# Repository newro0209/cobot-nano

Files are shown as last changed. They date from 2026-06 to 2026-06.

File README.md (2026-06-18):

# cobot-nano

SCARA robot arm, 3D-printed (FDM). Off-the-shelf parts (NopSCADlib vitamins)
maximized.

## Design
- **SCARA** kinematic chain: vertical Z translation (J1) + horizontal shoulder
  and elbow rotation (J2/J3) + tool roll (J4). See [docs/kinematic_chain.md](docs/kinematic_chain.md).
- **3D-printed (FDM)**, off-the-shelf parts maximized. Recesses, counterbores
  and press-fit seats are used freely; high-load seats are machined after
  printing (`[CNC-LATER]`).

## Layout
```
config.scad        shared spec, allowances, render settings; NopSCADlib + local vitamin includes
vitamins/          local vitamins not in NopSCADlib (mirror NopSCADlib's family-per-file layout)
  screws.scad        local M6_shoulder_screw added to NopSCADlib's screw family
  pulleys.scad       local GT2x60x8_pulley added to NopSCADlib's pulley family
parts/             fabricated parts (NopSCADlib printed/ analog) — 2D profile + extrude/pockets per module
assemblies/        integrated robot assembly preview — parts + vitamins, exploded view
docs/              kinematic chain, BOM
main.scad          full robot + animation hooks (incomplete scaffolding)
export/            cut-file generation (not yet wired)
```

## Conventions
Structure and style follow **NopSCADlib's actual layout first, then
`OPENSCAD_CONVENTIONS.md`**. There is no `plates/` / `fabrications/` split;
fabricated parts live in `parts/` like NopSCADlib's `printed/`. See `CLAUDE.md`.

## Workflow
1. Tune shared values in `config.scad` and subsystem values in
   `parts/arm_carriage_plate_base.scad`.
2. Preview: open `assemblies/robot_assembly.scad` in OpenSCAD
   (use the `bc_exploded`, `ac_exploded`, and `ua_exploded` sliders to explode stacks).
3. Headless check: `openscad -o out.echo assemblies/robot_assembly.scad`
   (only NopSCADlib's internal `2p54` deprecation should appear).

## BOM
See [docs/BOM.md](docs/BOM.md) for the arm carriage bill of materials with
CAD-derived dimensions (plate thickness, screw lengths, spacer heights).

## NopSCADlib (required)
NopSCADlib must be installed in your OpenSCAD libraries folder:
```
git clone https://github.com/nophead/NopSCADlib.git \
  "$HOME/Documents/OpenSCAD/libraries/NopSCADlib"
```
This machine's actual path: `C:\Program Files\OpenSCAD\libraries\NopSCADlib`.

Project vitamin files mirror NopSCADlib's family-per-file pattern only for parts
not provided by NopSCADlib (e.g. `M6_shoulder_screw`, `GT2x60x8_pulley`).
Existing NopSCADlib vitamins are used directly, without local wrappers.

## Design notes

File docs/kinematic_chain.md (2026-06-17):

# 기구 체인 (Kinematic Chain)

조립체·부품 명명은 아래 운동 체인을 기준으로 맞춘다.

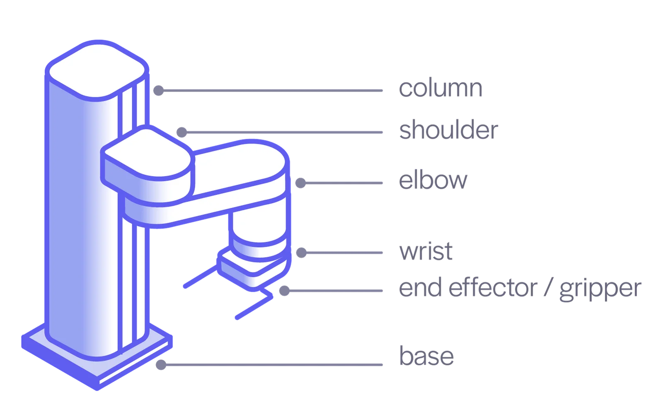
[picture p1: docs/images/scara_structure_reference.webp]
SCARA 구조 참조


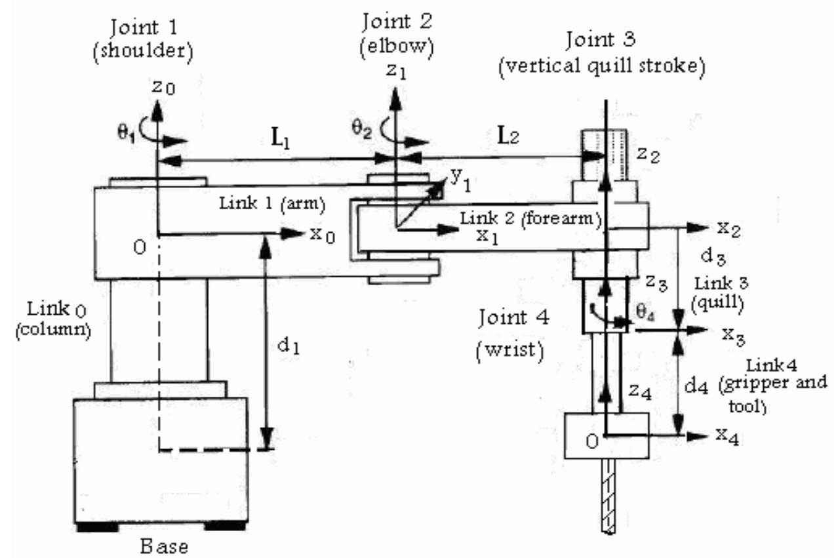
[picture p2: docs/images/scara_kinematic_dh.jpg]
SCARA DH 기구 다이어그램


```text
BASE_MOUNTING_PLATE      베이스 고정판(base mounting plate)   (고정)
-> BASE_COLUMN           베이스 기둥(base column)            (고정)
-> COLUMN_Z_SLIDE (J1)   Z 레일(Z rail)                     — Z축 병진(수직 이동)
-> ARM_CARRIAGE          암 캐리지(arm carriage)             — Z 레일 이동체, 어깨 관절 마운트
-> SHOULDER_MOUNT_LINK   어깨 마운트 링크(shoulder mount link) — 암 캐리지에서 J2 축까지 돌출된 링크
-> SHOULDER_JOINT (J2)   어깨 관절(shoulder joint)           — 수평 회전, 상완 선회
-> UPPER_ARM             상완 링크(upper arm)
-> ELBOW_JOINT (J3)      팔꿈치 관절(elbow joint)            — 수평 회전, 전완 선회
-> FOREARM               전완 링크(forearm)
-> TOOL_ROLL (J4)        툴 롤(tool roll)                   — Z축 회전, 공구 방향
-> TOOL_FLANGE           툴 플랜지(tool flange)
```

링크의 양끝은 기준부에 가까운 쪽을 `proximal pivot`(근위 피벗), 말단부에 가까운 쪽을 `distal pivot`(원위 피벗)으로 부른다.

```text
[proximal pivot] ── link body ── [distal pivot]
[근위 피벗]        ── 링크 몸체 ──  [원위 피벗]
```

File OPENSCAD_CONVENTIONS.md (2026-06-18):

---
name: openscad-conventions
description: 이 프로젝트에서 OpenSCAD 파라메트릭 모델을 설계, 구현, 수정, 리뷰할 때 적용하는 코딩 컨벤션.
version: 2.0-openscad
---

# OpenSCAD 코딩 컨벤션

> OpenSCAD는 선언형·함수형 CAD 언어다. 변수는 컴파일 시점에 확정되는 불변값이며, 재할당·반복 누적·예외 처리·객체지향 개념이 없다. 이 문서는 그 특성에 맞춰 작성되었다.

## 규칙 강도 표기

| 표기 | 의미 |
|---|---|
| **MUST** | 반드시 따른다. 위반은 잘못된 구현으로 간주한다. |
| **NEVER** | 어떤 경우에도 금지한다. |
| **SHOULD** | 기본으로 따른다. 위반 시 사유를 명시한다. |

## 충돌 시 우선순위

이 문서보다 **NopSCADlib 실제 구조/스타일**이 먼저다(프로젝트 지시: NopSCADlib → 이 문서 순). NopSCADlib가 정하지 않은 부분에서 규칙이 충돌하면 아래 항목이 우선한다.

1. **현재 부품·요구의 정확한 충족** — 지금 필요 없는 파라미터·옵션은 만들지 않는다 (YAGNI)
2. **읽기 쉬움** — 한 번에 이해되지 않는 모델은 잘못된 설계다 (KISS)
3. **의미 보존** — 이름과 구조가 기계 부품의 의미를 드러내야 한다
4. **중복 제거** — 의미를 해치면 형상 중복을 허용한다 (DRY는 최하위)

---

## 1. 네이밍 [N]

### N-1 (MUST) 이름만으로 부품·치수의 역할을 추론할 수 있어야 한다

OpenSCAD 관례에 따라 모듈·함수·변수는 `snake_case`로 작성한다.

| ✅ 권장 | ❌ 금지 |
|---|---|
| `gt2_pulley`, `bearing_seat_608zz` | `part1`, `obj`, `thing` |
| `joint_actuator_housing` | `data`, `temp`, `stuff` |
| `belt_anchor_clamp` | `helper`, `util`, `make` |
| `shoulder_bolt_clearance` | `val`, `x1`, `do_it` |

### N-2 (MUST) CAD 표준 치수 약어만 허용한다

다음 한 글자 약어는 CAD·OpenSCAD 관례상 허용한다.

> `r`(반지름) · `d`(지름) · `h`(높이) · `w`(폭) · `t`(두께) · `od`/`id`(외경/내경) · `$fn`/`$fa`/`$fs`(해상도)

그 외 임의 단축어는 금지한다. 단, N-4의 부품 패밀리 접두사처럼 파일·타입 스키마가 정의한 짧은 도메인 prefix는 임의 단축어로 보지 않는다.

| ❌ 금지 | ✅ 권장 |
|---|---|
| `cfg`, `cnt`, `tol` | `configuration`, `count`, `clearance` |
| `brg`, `plt` | `bearing`, `pulley` |
| `dia` | `diameter` (또는 `d`) |

### N-3 (SHOULD) 짧은 이름보다 오해 없는 이름

`wall` → `mounting_wall_thickness`, `gap` → `axial_clearance`
단, 명확한 지역 변수(루프 인덱스 `i`, 각도 `a`)는 예외다.

### N-4 (MUST) 단일 프로젝트 설정값에는 반복 접두사를 붙이지 않는다

이 저장소처럼 단일 로봇을 모델링하는 프로젝트는 파일과 프로젝트가 이미 맥락을 제공하므로 설정 변수에 `design_`, `spec_`, `cobot_` 같은 반복 접두사를 붙이지 않는다. 공통 기준값은 `config.scad`에 두고, 특정 부품 패밀리의 기준값과 타입 배열은 해당 plural 파일에 둔다.

단, NopSCADlib와 로컬 타입 배열의 접근자 함수는 T-2에 따라 `prefix_property(type)` 형식을 유지한다. 여러 파일이 같은 부품 패밀리의 공통 기준값을 include해 공유하는 경우에도 NopSCADlib처럼 짧고 안정적인 패밀리 prefix를 쓴다. 예를 들어 `arm_carriage_plate_base.scad`가 제공하는 전역 치수·좌표는 긴 `arm_carriage_*` 대신 `ac_*`를 사용한다.

```scad
// config.scad
sheet_thickness = 6;
main_bolt_diameter = 5;

// parts/links.scad
lower_link_length = 200;
upper_link_length = lower_link_length * upper_link_length_ratio;

// parts/arm_carriage_plate_base.scad
ac_leadnut_type = LSN8x2;
ac_motor_center = [0, 0];
ac_plate_thickness = bb_width(ac_driven_axis_ball_bearing_type) + seat_shoulder_thickness;
```

---

## 2. 파일 구조와 책임 분리 [S]

### S-1 (MUST) 파일을 다음 순서로 구성한다

```text
1. 파라미터 블록   — 모든 설정 가능한 치수·공차를 상단에 모은다
2. 함수            — 순수 계산 (피치 지름, 좌표 생성 등)
3. 부품 모듈       — 출력·가공 단위가 되는 개별 부품
4. 어셈블리 모듈   — 부품을 조합해 배치 (시각화·간섭 확인용)
5. 렌더 선택부     — 무엇을 출력할지 고르는 진입점
```

### S-2 (MUST) 한 모듈 = 한 부품, 한 함수 = 한 계산

하나의 모듈은 하나의 출력·가공 단위(또는 하나의 기능적 형상)만 담당한다.

### S-3 (MUST) 매직 넘버를 금지한다 — 모든 치수는 명명된 파라미터로

특히 **공차·클리어런스**는 반드시 명명 변수로 분리한다. 프린터·가공 방식이 바뀌면 한 곳만 고치면 되도록 한다.

```text
// 제조 공차 (한 곳에서 관리)
fdm_clearance      = 0.2;   // PETG FDM 압출 공차(extrusion tolerance)
press_fit_interference = 0.05; // 608ZZ 베어링 압입 간섭(interference fit)
axial_clearance    = 0.3;   // 회전 허브-인접부 축방향 간격(axial gap)
```

### S-4 (NEVER) 미래 부품을 가정한 파라미터·옵션 선제작 금지

지금 만드는 부품에 필요 없는 분기·옵션 인자를 미리 넣지 않는다.

### S-5 (MUST) 형상 공통화 게이트 — 아래를 **모두** 만족할 때만 모듈로 추출한다

1. 동일 형상이 **3회 이상** 반복됨
2. 의미가 동일함 (우연히 모양만 같은 것은 중복이 아님)
3. 추출 후 이름이 더 명확해짐
4. 치수 변경 방향이 같다고 확신할 수 있음

하나라도 불충족 → 형상을 그대로 둔다. 볼트 구멍 하나를 성급히 모듈화하지 않는다.

### S-6 (MUST) `config.scad`와 plural 파일의 기준값 책임을 분리한다

`config.scad`에는 제조 공차, 렌더 해상도, 체결 부품 선택처럼 여러 계층이 공유하는 기준값을 둔다. 특정 서브시스템의 치수·좌표·타입은 해당 part 파일에서 짧은 패밀리 접두사로 둔다.

```scad
// config.scad
clearance = 0.1;
$fn = 56;
main_bolt_diameter = 5;

// parts/arm_carriage_plate_base.scad
ac_plate_thickness = bb_width(ac_driven_axis_ball_bearing_type) + seat_shoulder_thickness;
ac_motor_center = [0, 0];
```

### S-7 (MUST) 연결된 치수는 비율로 파생한다

직접 mm 값을 두는 대상은 기준 링크 길이, 판재 두께, 볼트 지름처럼 외부 제약이나 설계 의사결정으로 독립적으로 정해지는 값으로 제한한다. lazy-susan처럼 외부 부품을 선택하는 타입도 독립 기준으로 볼 수 있다. 그 기준에 연결된 길이·간격·폭은 별도 mm 값으로 다시 쓰지 않고 비율이나 함수로 계산한다.

```scad
// parts/links.scad
lower_link_length = 200;
upper_link_length_ratio = 1.2;
link_width_ratio = 0.15;

upper_link_length = lower_link_length * upper_link_length_ratio;
link_width = lower_link_length * link_width_ratio;

// config.scad
base_bearing = BB6808;
base_diameter_ratio = 1.6;
base_diameter = bb_diameter(base_bearing) * base_diameter_ratio;
```

### S-8 (NEVER) 로봇 전체 설계를 타입 배열/접근자 레이어로 감싸지 않는다

타입 배열과 `prefix_property(type)` 접근자는 NopSCADlib식 vitamin 데이터처럼 독립 부품의 스키마가 명확할 때 사용한다. 로봇 전체 어셈블리의 임시 설계값을 배열 하나와 수십 개의 접근자 함수로 감싸지 않는다.

### S-9 (MUST) 부품·vitamin·조립체 계층을 분리한다 (NopSCADlib 구조)

3D 프린팅 프로젝트는 NopSCADlib 구조를 따른다.

```text
vitamins/      구입 부품 — NopSCADlib에 없는 로컬 타입만(패밀리당 한 파일로 미러링)
parts/         제작(프린트) 부품 — NopSCADlib printed/ 대응, 2D 프로파일 + 압출/포켓을 한 모듈에
assemblies/    parts와 vitamins를 배치해 기능 조립체 구성
```

`parts/`는 인터페이스 치수를 NopSCADlib 접근자로 읽고 하드코딩하지 않는다. `assemblies/`는 `parts/`와 `vitamins/`를 배치한다. 옛 `plates/`·`fabrications/` 2D 절단 분리는 쓰지 않는다(NopSCADlib에 없는 구조).

### S-10 (MUST) 같은 스키마의 2D 프로파일 변형은 타입 배열로 통합한다

같은 기계적 의미와 스키마를 가진 2D 프로파일이 여러 개 필요하면 개별 파일과 개별 모듈을 늘리지 않는다. 단일 프로파일 파일에 타입 배열 스키마, `prefix_property(type)` 접근자, `prefix_2d(type)` 모듈을 두고, 타입 인스턴스는 같은 폴더의 plural 파일에서 정의한다.

```scad
function link_length(type) = type[1];

module link_2d(type) {
    // 피벗 구멍(pivot hole)은 회전 조인트(revolute joint)가 축 기준으로 움직일 조립 여유(clearance)를 만든다.
    // ...
}

// parts/links.scad
//                name          length             width       bolt_diameter       profile_width_ratio
lower_link_type = ["lower_link", lower_link_length, link_width, main_bolt_diameter, 1.0];
upper_link_type = ["upper_link", upper_link_length, link_width, main_bolt_diameter, 1.0];
```

단, 우연히 모양만 같고 설계 변경 방향이나 기계적 의미가 다르면 S-5에 따라 공통화하지 않는다.

---

## 3. 타입 배열과 접근자 함수 [T]

NopSCADlib는 객체처럼 보이는 부품 데이터를 배열로 표현한다. 배열의 0번 요소는 대체로 이름이나 코드이고, 이후 요소는 치수와 속성이다.

```scad
BB608 = ["608", 8, 22, 7, "black", 1.4, 2.0, 0, 0];
```

### T-1 (MUST) 타입 배열은 기존 인덱스 방식으로 정의한다

배열 인덱스는 타입 정의부와 접근자 함수 내부에만 둔다. 호출부에 `type[2]` 같은 직접 접근을 노출하지 않는다.

### T-2 (MUST) 접근자 함수는 `prefix_property(type)` 형식을 따른다

접근자 함수는 짧고 안정적인 접두사를 사용한다. 기존 파일에서 쓰는 접두사가 있으면 바꾸지 않는다.

```scad
function bb_name(type)     = type[0]; //! Part code without shield type suffix
function bb_bore(type)     = type[1]; //! Internal diameter
function bb_diameter(type) = type[2]; //! External diameter
```

파생값도 접근자 함수로 표현한다. 원본 배열에 중복 저장해서 불일치를 만들지 않는다.

```scad
function gridfinity_bin_size_mm(type) =
    gridfinity_bin_size(type) * gridfinity_pitch();
```

### T-3 (SHOULD) 생성자 함수는 필요한 경우에만 둔다

복잡한 printed part처럼 사용자가 타입 배열을 직접 만들 가능성이 높으면 생성자 함수를 둘 수 있다. 생성자 이름은 대상 타입명과 같게 두는 기존 패턴을 우선한다.

```scad
function knob(name = "knob", top_d = 12, bot_d = 15, height = 18, shaft_length, ...) =
[
    name, top_d, bot_d, height, ...
];
```

### T-4 (MUST) 배열 스키마 주석을 유지한다

타입 목록 파일에는 열 의미를 알려주는 정렬 주석을 유지한다. 새 필드를 추가하면 주석, 접근자 함수, 타입 목록, 테스트를 함께 갱신한다.

```scad
//          name     id od   w    color
BB608    = ["608",   8, 22,  7,   "black"];
```

---

## 4. 모듈과 함수 [M]

### M-1 (MUST) 역할을 분리한다 — 모듈은 형상, 함수는 값

- **module**: 지오메트리를 생성한다. 값을 반환하지 않는다.
- **function**: 값을 계산해 반환한다. 형상을 만들지 않는다.

```text
// 함수: 값 계산
function gt2_pitch_diameter(teeth, pitch = 2) = teeth * pitch / PI;

// 모듈: 형상 생성
module gt2_pulley(teeth, bore_diameter, height) {
  assert(teeth > 0, "치아 수(teeth)는 양수여야 합니다");
  // ...
}
```

### M-2 (MUST) 명명 인자와 기본값을 사용한다 — 불리언·위치 인자 나열 금지

호출부에서 각 숫자의 의미가 드러나야 한다.

```text
❌ belt_anchor(12, 3, 5, true, false)
✅ belt_anchor(clamp_width = 12,
               bolt_diameter = 3,
               wall = 5,
               dual_end = true)
```

### M-3 (SHOULD) 반복·배치는 `children()`을 받는 고차 모듈로 분리한다

배치 로직과 형상 정의를 섞지 않는다.

```text
module radial_array(count, radius) {
  for (i = [0 : count - 1])
    rotate([0, 0, i * 360 / count])
      translate([radius, 0, 0])
        children();
}

radial_array(count = 6, radius = 20) bolt_hole(d = 3);
```

### M-4 (SHOULD) 불리언 연산 중첩을 평평하게 유지한다

`difference`/`union`이 3단계 이상 깊어지면 의미 있는 중간 모듈로 분리한다.

---

## 5. 선언적·파라메트릭 설계 [P]

### P-1 (MUST) 명령형 누적 대신 리스트 컴프리헨션으로 표현한다

OpenSCAD에는 가변 상태가 없다. 반복 데이터는 선언적으로 생성한다.

```text
// 섹터 기반 구동 요소의 둘레 좌표
tooth_points = [ for (a = [0 : tooth_angle : 360 - tooth_angle])
                   [cos(a) * pitch_r, sin(a) * pitch_r] ];
```

### P-2 (MUST) 함수 내 지역 바인딩은 `let()`으로 명시한다

```text
function planetary_output_speed(input_rpm, ratio) =
  let (output = input_rpm / ratio)
  output;
```

### P-3 (SHOULD) 2D 스케치 후 압출하는 선언적 패턴을 우선한다

`linear_extrude`, `rotate_extrude`로 단면을 먼저 정의하면 의도가 분명해지고 수정이 쉽다. 3D 프리미티브를 즉흥적으로 깎는 방식보다 우선한다.

### P-4 (MUST) 파생 치수는 저장하지 말고 함수로 계산한다

피치 지름, 중심 거리처럼 다른 값에서 계산되는 치수는 별도 변수로 중복 정의하지 않고 함수로 도출한다. 원본 치수와 파생 치수가 어긋나는 것을 방지한다.

---

## 6. 검증과 해상도 [V]

### V-1 (MUST) 기하학적 전제는 `assert()`로 강제한다

벽 두께가 음수가 되거나 구멍이 외경보다 큰 경우처럼 물리적으로 불가능한 입력을 컴파일 시점에 차단한다.

```text
module bearing_seat(outer_diameter, wall) {
  assert(wall > 0, "벽 두께(wall)는 0보다 커야 합니다");
  assert(outer_diameter > 0, "외경(outer diameter)은 양수여야 합니다");
  // ...
}
```

### V-2 (SHOULD) 디버깅 값은 `echo()`로 노출한다

조립 간섭이나 계산된 중심 거리 같은 핵심 수치를 콘솔로 확인할 수 있게 한다.

```text
echo(belt_center_distance = gt2_center_distance(driver_teeth, driven_teeth));
```

### V-3 (MUST) 해상도를 의도적으로 관리한다

- 전역 기본은 `$fa`/`$fs`로 설정한다.
- 특정 부품에만 높은 해상도가 필요하면 해당 모듈에서 `$fn`을 지역 지정한다.
- 모든 형상에 무분별하게 큰 `$fn`을 박지 않는다. 미리보기·렌더 시간이 폭증한다.

---

## 7. 주석 [C]

### C-1 (MUST) 주석은 "왜"만 설명한다

치수의 출처나 비자명한 제약의 이유를 적는다. 코드가 명백히 보여주는 것은 반복하지 않는다.

```text
❌ // 원기둥을 만듭니다.
✅ // 6810ZZ 외경 65mm + 압입 간섭 0.05mm 기준
   bearing_bore = 65 - press_fit_interference;
```

### C-2 (MUST) 주석과 문서는 한국어로 작성한다. 기계 용어는 한국어(영어) 병기한다

예: `// 숄더 볼트(shoulder bolt)가 고정축 역할을 하므로 베어링 내경에 맞춘다`

### C-3 (MUST) 파일 최상단 주석은 영어 설명 뒤 한국어 요약을 붙인다

파일 최상단 주석은 먼저 영어 문단으로 파일의 역할과 계층을 설명하고, 바로 뒤에 한국어 요약을 붙인다. 영어 설명은 외부 라이브러리·툴과 함께 읽히는 파일 헤더 역할을 하고, 한국어 요약은 프로젝트 내부 의사결정을 빠르게 확인하기 위한 것이다.

```scad
// parts/ball_bearing_seat.scad - Ball-bearing seat geometry cut into / added to printed plates (NopSCADlib printed-part style).
// Dimensions come from a NopSCADlib ball-bearing type so the seat tracks the bought bearing, not a hardcoded number.
//
// 베어링을 앉히기 위해 프린트 판재에 깎거나(음형) 덧대는(양형) 제작 형상이다.
// 치수는 NopSCADlib 베어링 타입에서 접근자로 읽어 하드코딩을 피한다.
```

### C-4 (MUST) 모듈 내부 주석은 한국어로 쓰고, 기계 원리를 설명한다

모듈 내부 주석은 한국어를 사용한다. 기계공학과 관련된 전문 용어는 반드시 `한국어(영어)` 형식으로 병기하고, 단순 명칭만 적지 말고 그 구조가 어떤 원리로 쓰이는지 설명한다.

```scad
// 외륜 림(outer-race rim)만 단차로 물어, 회전하는 내륜(inner race)과 실드를 건드리지 않는다.
translate(ac_driven_axis_center)
    bb_bearing_seat_pocket(ac_driven_axis_ball_bearing_type, part_thickness = ac_plate_thickness, from_top = true);
```

### C-4a (MUST) `seat_shoulder_thickness`는 파는 깊이가 아니라 남기는 두께다

포켓·시트에서 `seat_shoulder_thickness`는 **반대쪽에 남길 축방향 지지 두께**다. 카운터보어 또는 리세스 깊이는 `part_thickness - seat_shoulder_thickness`에서 계산해야 하며, 각 단계를 `seat_shoulder_thickness`만큼만 파는 값으로 쓰지 않는다.

```scad
// 권장: 가장 깊은 리세스 뒤에 shoulder를 남긴다.
seat_depth = part_thickness - seat_shoulder_thickness;
cylinder(d = seat_diameter, h = seat_depth + eps);

// 금지: shoulder 두께만큼만 시트를 얕게 판다.
cylinder(d = seat_diameter, h = seat_shoulder_thickness + eps);
```

다단 포켓은 얕은 단부터 깊은 단까지 누적 깊이로 계산한다. 예를 들어 모터 시트는 `body_recess_depth + NEMA_boss_height(type) == part_thickness - seat_shoulder_thickness`가 되도록 잡고, 샤프트 보어처럼 실제 관통이 필요한 형상만 남은 shoulder를 통과시킨다.

### C-5 (SHOULD) 코드 옆 주석은 `대상 용어(구) — 역할/이유(절)` 형식으로 쓴다

코드 바로 옆 주석은 `대상 용어(English term) — 역할/이유` 형식으로 쓴다. 앞의 **대상 용어는 짧은 구(phrase)**로, 뒤의 **역할/이유는 동사로 끝나는 절(clause)**로 쓴다(역할/이유를 명사구로 끊지 않는다). 기계적 역할과 제약이 한눈에 읽히도록 하고, `공칭 지름(nominal diameter, 호칭 치수)`처럼 오해될 수 있는 전문어는 괄호 안에 영어와 짧은 해석을 함께 붙인다.

```scad
// 외륜 숄더(outer-race shoulder) — 내륜(inner race) 바깥에서만 축방향으로 받쳐, 회전하는 내륜과 실드를 건드리지 않는다.
circle(d = inner_race_outside_diameter + bearing_clearance);
```

대상 용어가 자명하면 `—` 없이 역할/이유 절만 써도 된다. 단, 파일 헤더처럼 독립 문맥이 필요한 주석이나 복잡한 설계 의사결정은 C-1에 따라 여러 문장으로 이유를 설명할 수 있다.

### C-6 (SHOULD) 후속 가공 부위는 `[CNC-LATER]` 태그로 표기한다

FDM 프로토타입 후 절삭 가공할 구조적 임계부를 주석으로 명시해 추후 검색·교체가 쉽도록 한다.

```text
// [CNC-LATER] 고하중 피벗(high-load pivot) 베어링 시트, 프린트 후 보링 가공
```

---

## 8. 외부 라이브러리 [L]

### L-1 (MUST) `use`와 `include`를 구분해 쓴다

- `use <lib.scad>`: 모듈·함수만 가져온다 (최상위 형상 실행 안 함). **기본값**.
- `include <lib.scad>`: 파일 전체를 펼친다. 최상위 형상이 함께 실행되므로 신중히 쓴다.

### L-2 (MUST) 부품을 만들기 전에 NopSCADlib 존재 여부를 먼저 확인한다

기성품, 체결 부품, 모터, 베어링, 풀리처럼 vitamin 성격의 부품은 직접 모델링하거나 치수를 하드코딩하기 전에 `NopSCADlib/vitamins`에 같은 부품이 있는지 확인한다.

- 있으면 NopSCADlib의 타입 배열, 접근자 함수, 모듈을 그대로 사용한다.
- 없으면 프로젝트 `vitamins/`에 NopSCADlib의 단수/복수 파일 패턴으로 로컬 vitamin을 만든다.
- 확인 없이 로컬 모델, 래퍼, 임의 치수 상수를 만들지 않는다.

### L-3 (MUST) 라이브러리 부품 치수는 접근자로 읽는다

NopSCADlib가 제공하는 타입 배열의 치수는 숫자로 복사하지 않는다. 호출부와 제작 파트는 라이브러리 접근자를 통해 값을 읽는다.

```scad
// 금지: NEMA17 값 복사
NEMA17_HOLE = 31;
NEMA17_BORE = 23;

// 권장: NopSCADlib 접근자 사용
hole_pitch = NEMA_hole_pitch(NEMA17_40);
boss_clearance_r = NEMA_big_hole(NEMA17_40);
body_width = NEMA_width(NEMA17_40);
```

로컬 vitamin도 같은 원칙을 따른다. 예를 들어 lazy-susan의 외경과 장착 홀 피치는 `ls_diameter(type)`, `ls_bolt_circle_diameter(type)`처럼 접근자로 읽는다.

### L-4 (MUST) 라이브러리 도입 게이트 — 모두 만족할 때만 도입한다

1. 직접 구현보다 유지 비용이 낮음 (예: BOSL2의 나사산·기어)
2. 유지보수 상태가 안정적
3. 모델 핵심 복잡도를 실제로 줄임
4. 기존 코드·치수 체계와 충돌하지 않음

### L-5 (NEVER) 라이브러리가 이미 제공하는 vitamin을 의미 없이 래핑하지 않는다

NopSCADlib처럼 타입 배열, 접근자 함수, 모듈을 이미 제공하는 부품은 원래 파일과 이름을 그대로 사용한다. 프로젝트 파일은 라이브러리에 없는 부품을 추가하거나, 실제로 다른 인터페이스·의미를 제공할 때만 만든다.

---

## 9. 조립 라벨 오버레이 [A]

조립체(`assemblies/`)에는 부품을 지목하는 프리뷰 전용 라벨 오버레이를 둘 수 있다. 구현은 `assemblies/annotations.scad`(빌보드 텍스트·지시선·자동 배치 모듈)와 호출부(`robot_assembly.scad`의 assembly section별 label module)를 기준으로 한다.

### A-1 (MUST) 라벨은 `$preview` 전용이며 형상에 영향을 주지 않는다

모든 라벨 모듈은 `$preview` 가드 안에서만 그리고, 글자는 얇은 `linear_extrude`로 만든다. STL·절단·간섭 형상에는 들어가지 않는다.

### A-2 (SHOULD) 라벨 위치는 고정값이 아니라 뷰포트와 부품 좌표로 계산한다

지시선 lead를 손으로 박지 않는다. 부품 점과 뷰포트 회전(`$vpr`)에서 화면축(화면 우/상/법선)을 유도해 라벨을 화면 좌/우 열에 자동 분배하고, 열 안에서 균등 간격으로 펼쳐 겹치거나 가리지 않게 한다(`callout_field`). 카메라를 돌리면 라벨도 따라 재배치된다.

### A-3 (MUST) 라벨 색은 대상 부품의 렌더 색과 같게 한다

부품 색을 한 곳(예: `asm_col_*`)에 정의해 그리기와 라벨이 같은 변수를 공유한다. 라벨·지시선·점을 그 색으로 그려 어느 부품을 가리키는지 색으로도 잇는다. 내부 고정색 vitamin(NopSCADlib 모터·베어링·체결구)은 재질색으로 근사한다. 글자 가독성을 위해 명도 기준 대비 테두리(`contrast_outline`)를 덧댄다 — 회색 계열은 RGB 보색이 다시 회색이라 대비가 안 나므로 흑/백을 쓴다.

### A-4 (MUST) exploded에서 라벨은 대상과 같은 변환으로 따라 움직인다

부품이 받는 분해 변환(거리비례 bloom + explode Z)을 라벨 점에도 그대로 적용한다(`label_point`). 분해해도 라벨이 부품에 붙어 있어야 한다.

### A-5 (SHOULD) 라벨은 종류 토글로 끄고 켠다

기능군으로 토글을 나눈다 — 체결구 / 구조·개념(관절·축·링크) / 동적 기성품(모터·풀리·벨트·베어링·이송나사). 체결구는 라벨만 보고 조립할 수 있을 만큼 위치·역할까지 빠짐없이 달고(중복 허용), 구조는 J1/J2 같은 관절·축과 링크 개념을 빠짐없이 단다. 데이터 스키마는 `[텍스트, 점, 그룹, 강조, bloom, ez, 색]`을 쓴다.

---

## 작업 절차

부품 추가·수정 시 아래 순서를 따른다.

1. 만들 부품을 **한 문장**으로 정의한다 (예: "608ZZ 2개를 지지하는 J2 팔꿈치 베어링 하우징")
2. 해당 부품이나 인접 vitamin이 NopSCADlib에 있는지 먼저 확인한다 (L-2)
3. NopSCADlib에 있으면 원본 타입·모듈·접근자로 인터페이스 치수를 읽는다 (L-3)
4. 인접 부품과의 인터페이스 치수·공차를 먼저 파라미터로 정리한다
5. 파생 치수를 함수로 분리한다
6. 2D 단면 → 압출 가능한지 먼저 검토한다
7. 제작 부품은 `parts/`에 NopSCADlib printed/ 스타일로 두고, 구입 부품은 `vitamins/`에 둔다 (S-9)
8. 같은 스키마의 반복 2D 프로파일이면 타입 배열과 접근자 함수로 통합한다 (S-10, T-1, T-2)
9. 이름을 확정한 뒤 모듈을 구현한다
10. 반복 형상은 즉시 모듈화하지 말고 S-5 게이트를 검사한다
11. `assert()`로 기하 전제를 건다
12. 더 단순하게 줄일 수 있는지 마지막으로 검토한다

---

## 셀프 리뷰 체크리스트

제출 전 **모든** 항목을 통과해야 한다.

- [ ] 이름만 보고 부품·치수 역할을 이해할 수 있는가? (N-1)
- [ ] 공통 기준값은 `config.scad`, 특정 부품 패밀리 값과 타입 배열은 plural 파일에 있으며 반복 접두사를 쓰지 않는가? (N-4, S-6)
- [ ] 매직 넘버 없이 공차·치수가 명명 파라미터로 분리됐는가? (S-3)
- [ ] vitamin 성격의 부품을 만들기 전에 NopSCADlib 존재 여부를 확인했는가? (L-2)
- [ ] NopSCADlib 제공 부품의 치수를 숫자로 복사하지 않고 접근자로 읽는가? (L-3)
- [ ] 부품·vitamin·조립체 계층이 `parts/`, `vitamins/`, `assemblies/`로 분리됐는가? (S-9)
- [ ] 타입 배열을 직접 인덱싱하지 않고 접근자 함수로만 읽는가? (T-1, T-2)
- [ ] 같은 스키마의 반복 2D 프로파일을 개별 파일로 늘리지 않고 타입 배열로 통합했는가? (S-10)
- [ ] 타입 배열의 주석, 접근자 함수, 타입 목록, 테스트가 함께 갱신됐는가? (T-4)
- [ ] 한 모듈이 한 부품, 한 함수가 한 계산만 하는가? (S-2, M-1)
- [ ] 지금 부품에 불필요한 옵션을 미리 만들지 않았는가? (S-4)
- [ ] 형상 추출이 의미를 해치지 않았는가? (S-5)
- [ ] 호출부가 명명 인자로 읽히는가? (M-2)
- [ ] 파생 치수를 중복 저장하지 않고 함수로 도출했는가? (P-4)
- [ ] 물리적으로 불가능한 입력을 `assert()`로 막았는가? (V-1)
- [ ] 해상도(`$fn`/`$fa`/`$fs`)를 의도적으로 관리했는가? (V-3)
- [ ] 파일 최상단 주석이 영어 설명 뒤 한국어 요약 형식인가? (C-3)
- [ ] 모듈 내부 주석이 한국어이며 기계 용어를 한국어(영어)로 병기하고 원리를 설명하는가? (C-4)
- [ ] 불리언 연산 중첩이 평평하게 읽히는가? (M-4)
- [ ] 조립 라벨이 `$preview` 전용이고, 색은 대상과 같으며, exploded에서 함께 움직이는가? (A-1, A-3, A-4)

하나라도 실패하면 해당 규칙 ID 기준으로 수정한 뒤 재검사한다.

---

## 최종 판단 기준

이 문서와 충돌하는 모델보다, 이 문서에 맞춰 **단순하고 명확하게 다시 작성한 파라메트릭 모델**을 우선한다.

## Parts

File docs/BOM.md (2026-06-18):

# BOM

이 문서는 현재 `config.scad`와 `assemblies/robot_assembly.scad` 기준의 수동 BOM입니다.
수량이 실제 assembly에 배치된 항목과 config에만 선언된 상위 J1 인터페이스 항목을 분리합니다.
구매 전에는 OpenSCAD echo와 공급사 도면을 다시 확인합니다.

## Arm Carriage Assembly

`assemblies/robot_assembly.scad` 안의 `arm_carriage_assembly()` 스택에 실제 배치되는 캐리지 기준입니다.

| 분류 | 품목 | CAD 타입 / 사양 | 수량 | 비고 |
|---|---|---|---|---|
| 제작품 | Arm carriage top plate | `parts/arm_carriage_top_plate.scad`, t=9mm | 1 | 상판, J1 리드너트와 J2 모터 슬롯 포함 |
| 제작품 | Arm carriage bottom plate | `parts/arm_carriage_bottom_plate.scad`, t=9mm | 1 | 하판, J2 종동축 하부 베어링 시트 포함 |
| 모터 | J2 stepper motor | `NEMA17_47` | 1 | 어깨 회전 구동 모터 |
| 풀리 | J2 drive pulley | `GT2x20um_pulley`, GT2 20T | 1 | NEMA17 모터축 구동 풀리 |
| 풀리 | J2 driven pulley | `GT2x60x8_pulley`, GT2 60T, 8mm bore | 1 | 3:1 감속 출력 풀리, 로컬 vitamin |
| 벨트 | J2 closed-loop timing belt | `GT2x6` | 1 | 표준 후보 298..312mm, 권장 306mm |
| 베어링 | J2 ball bearing | `BB608` (8x22x7) | 2 | J2 종동축 상/하 지지 |
| 베어링 | J1 linear bearing | `LM8UU` | 3 | 3개 가이드 로드용 캐리지 베어링 |
| 리드너트 | J1 leadnut | `LSN8x2` | 1 | 상판 아랫면 시트에 장착 |
| 스탠드오프 | Female-female hex pillar | `M3x25_ff_hex_pillar`, M3 x 25mm | 4 | 활성 인덱스 `[0, 1, 3, 4]`; 모터 슬롯 쪽 `[2, 5, 6, 7]` 제외 |
| 체결류 | Standoff screws | `M3_cap_screw`, L=16mm + washer | 8 | 필러 4개 x 상/하 2개 |
| 체결류 | Leadnut flange screws | `leadnut_screw(LSN8x2)`, L=16mm + washer + nut | 4 | 리드너트 플랜지 체결 |
| 체결류 | J2 shoulder screw | `M6_shoulder_screw`, shoulder dia 8mm, CAD shoulder length 70.6mm + `M8_washer` (머리 밑) | 1 | BB608 보어와 상/하 FC 허브를 관통하는 J2 고정 피벗 |
| 체결류 | J2 shoulder locknut | `M6_nut` (nyloc) + `M6_washer` | 1 set | 하단 FC 아래에서 스택 축방향 고정 |
| 커플링 | J2 driven flange coupling | `FC8`, 8mm bore, 4×M4 볼트원 | 2 | 어깨축 상/하단 링크 마운트, 숄더 봉을 grub screw로 죔, 로컬 vitamin |

## Configured J1 Interface

다음 항목은 `config.scad`에 J1 축 인터페이스로 선언되어 있고, `robot_assembly.scad`의 base-column 쪽 배치를 기준으로 재점검이 필요합니다.

| 분류 | 품목 | CAD 타입 / 사양 | 기준 수량 | 비고 |
|---|---|---|---|---|
| 모터 | J1 stepper motor | `NEMA17_34` | 1 | Z 병진축 구동 모터 |
| 커플링 | J1 shaft coupling | `SC_5x8_rigid` | 1 | 모터 5mm 축과 T8 리드스크류 8mm 축 직결 |
| 리드스크류 | J1 lead screw | T8x2, 8mm shaft | 1 | 길이는 아직 BOM에서 확정하지 않음 |
| 베어링 블록 | J1 flange bearing block | `KFL08`, 8mm bore | 1 | 로컬 vitamin, 리드스크류 회전 지지 |
| 가이드 로드 | J1 guide rod | 8mm shaft | 3 | `LM8UU`와 `FC8` bore 기준 |
| 플랜지 커플링 | Guide rod flange coupling | `FC8`, 8mm bore | 각 로드 끝단 수량 확정 필요 | 가이드 로드 단판 고정용 로컬 vitamin |

## 주요 CAD 파생 치수

| 항목 | 값 | 출처 |
|---|----|---|
| 캐리지 판 두께 | 9mm | `ac_thickness = bb_width(BB608) + seat_shoulder_thickness` |
| 상/하판 사이 간격 | 25mm | `ac_plate_gap = pillar_height(standoff_pillar_type)` |
| J1 중심축 - J2 어깨축 거리 | 70mm | `shoulder_mount_link_length` |
| J2 모터 슬롯 이동량 | 8mm | `ac_j2_motor_slot_travel` |
| J2 풀리 중심거리 min/current/max | 108.15 / 112.15 / 116.15mm | `ac_j2_belt_distance_*` echo (current=모터 슬롯 위치) |
| J2 벨트 정확 길이 min/current/max | 297.801 / 305.747 / 313.697mm | `ac_timing_belt_length_*` echo |
| J2 GT2 표준 폐루프 벨트 후보 | 298..312mm, nominal 306mm | `ac_timing_belt_standard_*` echo |
| 스탠드오프 체결 스크류 길이 | 16mm | `ac_standoff_screw_length` |
| 리드너트 체결 스크류 길이 | 16mm | `screw_length(leadnut_screw(j1_leadnut_type), ac_thickness, 2, nut = true)` |
| J2 숄더 길이 계산값 | 70.6mm | `ac_j2_shoulder_length` (판 스택 + 2×`fc_height(FC8)` + 머리 와셔) |

## Local Vitamins

| 파일 | 타입 | 역할 |
|---|---|---|
| `vitamins/pulleys.scad` | `GT2x60x8_pulley` | J2 60T, 8mm bore 종동 풀리 |
| `vitamins/screws.scad` | `M6_shoulder_screw` | J2 BB608 보어용 8mm shoulder screw |
| `vitamins/pillars.scad` | `M3x25_ff_hex_pillar` | 상/하판 연결용 양끝 암나사 M3 필러 |
| `vitamins/flange_bearing_blocks.scad` | `KFL08` | J1 리드스크류용 8mm 플랜지 베어링 블록 |
| `vitamins/flange_couplings.scad` | `FC8` | J1 가이드 로드 단부 고정용 8mm 플랜지 커플링 |

## Notes

- J2 벨트 장력은 아이들러가 아니라 `ac_j2_motor_slot_travel` 범위에서 모터 전체를 -Y 방향으로 이동해 조절합니다.
- `GT2x60x8_pulley`, `M6_shoulder_screw`, `M3x25_ff_hex_pillar`, `KFL08`, `FC8`은 프로젝트 로컬 vitamin입니다.
- `M6_shoulder_screw`의 70.6mm는 CAD 계산 shoulder 길이입니다. 실제 구매 규격은 가장 가까운 표준 ISO 7379 shoulder length를 선택해야 합니다.
- J1 리드스크류 길이, 가이드 로드 길이, FC8 수량은 아직 현재 캐리지 assembly만으로 확정하지 않습니다.

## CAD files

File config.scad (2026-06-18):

// config.scad - Project-wide shared values for the cobot-nano arm carriage subsystem.
// Holds manufacturing allowances, render resolution, and shared geometry constants, and pulls in the
// NopSCADlib vitamin families plus the project-local vitamin extensions (vitamins/screws, vitamins/pulleys).
//
// 프로젝트 공통값 — 제조 공차(manufacturing allowance), 렌더 해상도, 공유 형상 기준값을 둔다.
// NopSCADlib vitamin 패밀리와 프로젝트 로컬 vitamin 확장(vitamins/screws, vitamins/pulleys)을 함께 가져온다.
// 작은 fudge 값(coincident-face 방지)은 NopSCADlib 전역 `eps`(=1/128)를 그대로 쓴다 — 별도 정의하지 않는다.

include <NopSCADlib/lib.scad>
include <vitamins/pillars.scad>               // 로컬 M3x25_ff_hex_pillar (+ NopSCADlib pillar 패밀리)
include <vitamins/screws.scad>                // 로컬 M6_shoulder_screw (+ NopSCADlib screw 패밀리)
include <vitamins/pulleys.scad>               // 로컬 GT2x60x8_pulley (+ NopSCADlib pulley 패밀리)
include <vitamins/rods.scad>                  // 로컬 J1_guide_rod / T8x2_lead_screw (+ NopSCADlib rod 모듈)
include <vitamins/flange_couplings.scad>      // 로컬 FC8 플랜지 커플링 (NopSCADlib 미수록)
include <vitamins/flange_bearing_blocks.scad> // 로컬 KFL08 플랜지 베어링 블록 (NopSCADlib 미수록)

// 제조 공차(manufacturing allowance) — 가공/프린트 방식이 바뀌면 여기 한 곳만 고친다.
clearance           = 0.1;  // 부품 간 일반 끼움 간격(general fit) — 간섭(interference) 방지
bearing_clearance   = 0.1;  // 베어링 시트(bearing seat)와 베어링 사이 — 조립 편차·윤활유 수용
shaft_clearance     = 0.5;  // 샤프트 관통홀(shaft through-hole) — 오차·회전축 조립 편차 흡수
min_printed_feature = 0.8;  // FDM 최소 인쇄 두께(≈2 레이어) — 이보다 얇은 부싱/스페이서는 인쇄 대신 와셔로 흡수해 생략

// 공유 형상 기준값(shared geometry)
seat_shoulder_thickness = 2;   // 포켓·리세스 바닥에 남기는 축방향 지지 단차(seat shoulder)
component_margin        = 6;  // 조립 부품 간 최소 간격 — 조립 편차·시각적 명확성 확보

// J1 축 중심 좌표
j1_axis_center = [0, 0];

// ── J1 축(Z 병진, prismatic joint) — 리드스크류로 캐리지를 수직 이송한다 ──
// 모터를 강성 커플링(rigid coupling)으로 리드스크류에 직결하고, 캐리지에 고정된 리드너트(lead nut)가
// 스크류 회전을 직선 이송으로 바꾼다. 가이드 로드(guide rod) 3개가 LM8UU로 캐리지를 직선 안내하고,
// 로드 양끝은 플랜지 커플링으로 단판(end plate)에 수직 고정된다.
j1_motor_type                = NEMA17_34;     // Z 이송 구동 모터
j1_shaft_coupling_type       = SC_5x8_rigid;  // 모터 5mm 축 ↔ 리드스크류 8mm 축 강성 직결
j1_lead_screw_type           = T8x2_lead_screw; // T8x2 리드스크류 — NopSCADlib leadscrew() 렌더 사양
j1_leadnut_type              = LSN8x2;         // T8x2 리드너트 — 회전을 병진으로 변환(리드 2mm/rev)
j1_flange_bearing_block_type = KFL08;          // 리드스크류 회전을 받는 플랜지 베어링 블록
j1_linear_bearing_type       = LM8UU;          // 가이드 로드 직선 베어링
j1_guide_rod_type            = J1_guide_rod;   // LM8UU와 FC8이 공유하는 8mm smooth guide rod
j1_flange_coupling_type      = FC8;            // 가이드 로드 끝을 단판에 수직 고정하는 커플링
// 가이드 로드는 LM8UU가 타는 봉이자 FC8이 무는 봉 — 한 봉을 공유하므로 두 부품의 호칭 지름이 같아야 한다.
assert(smooth_rod_diameter(j1_guide_rod_type) == bearing_rod_dia(j1_linear_bearing_type),
       "J1 가이드 로드 지름은 LM8UU 가이드 베어링 지름과 같아야 한다");
assert(smooth_rod_diameter(j1_guide_rod_type) == fc_bore(j1_flange_coupling_type),
       "J1 가이드 로드 지름은 FC 플랜지 커플링 보어와 같아야 한다");
assert(lead_screw_diameter(j1_lead_screw_type) == leadnut_bore(j1_leadnut_type),
       "J1 리드스크류 지름은 리드너트 보어와 같아야 한다");
assert(lead_screw_diameter(j1_lead_screw_type) == kfl_bore(j1_flange_bearing_block_type),
       "J1 리드스크류 지름은 KFL08 베어링 보어와 같아야 한다");
assert(lead_screw_lead(j1_lead_screw_type) == leadnut_lead(j1_leadnut_type),
       "J1 리드스크류 리드는 리드너트 리드와 같아야 한다");
assert(lead_screw_starts(j1_lead_screw_type) == leadnut_lead(j1_leadnut_type) / leadnut_pitch(j1_leadnut_type),
       "J1 리드스크류 starts는 리드너트 lead/pitch와 같아야 한다");
assert(lead_screw_length(j1_lead_screw_type) < smooth_rod_length(j1_guide_rod_type),
       "J1 리드스크류는 가이드 로드보다 짧아야 한다");
j1_guide_rod_diameter = smooth_rod_diameter(j1_guide_rod_type);
j1_guide_rod_count    = 3;  // 캐리지 3점 지지 — 단일 봉의 비틀림(yaw)·기울어짐(pitch)을 억제

// ── J2 축(어깨 회전, revolute joint) — GT2 타이밍벨트로 상완을 수평 회전한다 ──
// 모터 20T 구동 풀리 → GT2 벨트 → 60T 종동 풀리로 3:1 감속, 종동축은 BB608로 캐리지에 회전 지지된다.
j2_motor_type               = NEMA17_47;       // 어깨 회전 구동 모터(상완 하중 대응 긴 바디)
j2_drive_pulley_type        = GT2x20um_pulley;  // 모터축 20T 구동 풀리(NopSCADlib 기본)
j2_driven_ball_bearing_type = BB608;            // 종동축(어깨 피벗) 회전 지지 베어링
j2_driven_pulley_type       = GT2x60x8_pulley;  // 60T 종동 풀리 — 20:60 = 3:1 감속
j2_driven_shoulder_screw_type = M6_shoulder_screw;  // 어깨 피벗 고정 — 숄더부가 BB608 보어를 채우고 끝 나사산에 락너트가 물린다
j2_driven_flange_coupling_type = FC8;          // 어깨축 상/하단 링크 마운트 — 허브가 숄더 봉을 죄고 플랜지가 상/하 암 링크를 무다

// J1(중심축)에서 J2(어깨축)까지 수평 거리 — 캐리지 판이 두 축을 잇는 길이(기준 치수).
shoulder_mount_link_length = 100;

// J2 어깨축 중심 — J1 원점에서 +Y로 링크 길이만큼 떨어진 좌표.
j2_driven_axis_center = [0, shoulder_mount_link_length];

// ── J3 축(팔꿈치 회전, revolute joint) — GT2 타이밍벨트로 전완을 수평 회전한다 ──
// 모터 20T 구동 풀리 → GT2 벨트 → 60T 종동 풀리로 3:1 감속, 종동축은 BB608로 상완(upper arm)에 회전 지지된다.
// J3 모터는 상완 근위의 J2 축과 동축으로 둔다. 20T 구동 풀리가 같은 축에서 원위 J3 60T 종동 풀리를 구동한다.
j3_motor_type               = NEMA17_34;        // 팔꿈치 구동 모터 — 상완 끝단 하중이 작아 짧은 바디(필요시 변경)
j3_drive_pulley_type        = GT2x20um_pulley;   // 모터축 20T 구동 풀리(J2와 동일)
j3_driven_ball_bearing_type = BB608;             // 종동축(팔꿈치 피벗) 베어링 — 60T 종동 풀리 보어(8mm)에 맞춰 보어 8mm(J2와 동일)
j3_driven_pulley_type       = GT2x60x8_pulley;   // 60T 종동 풀리 — 20:60 = 3:1 감속(J2와 동일)
j3_driven_shoulder_screw_type = M6_shoulder_screw; // 팔꿈치 피벗 고정 — 숄더부가 BB608 보어(8mm)를 채우고 끝 나사산에 락너트(J2와 동일)
assert(pulley_belt(j3_drive_pulley_type) == pulley_belt(j3_driven_pulley_type),
       "J3 구동 풀리와 종동 풀리는 같은 벨트 타입이어야 한다");

// J2(어깨축)에서 J3(팔꿈치축)까지 수평 거리 — 상완 링크가 두 축을 잇는 길이(기준 치수, 상완 로컬 프레임).
upper_arm_length = 100;
// J3 팔꿈치축 중심 — 상완 로컬 원점(=J2 마운트)에서 +Y로 링크 길이만큼.
j3_elbow_axis_center = [0, upper_arm_length];

// 캐리지 스탠드오프 — 위·아래 캐리지 판을 잇는 M3 양끝 암나사 필러와 체결 볼트를 고른다.
// (볼트 서클 배치값은 형상 종속이라 arm_carriage_plate_base.scad의 ac_standoff_*에 둔다.)
standoff_pillar_type = M3x25_ff_hex_pillar;
standoff_screw_type = M3_cap_screw;

$fn = 56;  // 곡면 분할(facets) — vitamin·제작 형상 미리보기에 충분한 해상도

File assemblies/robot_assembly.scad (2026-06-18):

// assemblies/robot_assembly.scad — 단일 통합 로봇 어셈블리(통짜).
// J1 베이스 컬럼(Z 이송) → J2 암 캐리지(어깨) → J3 상완(팔꿈치)를 하나의 robot_assembly()로 렌더한다.
// 구성: 변수(파생값) → 함수 → 진단(echo/assert) → 모듈 순으로 종류별 분리. joint별 robot_j1_/j2_/j3_,
// 공용은 robot_. 남은 bc_/ac_/ua_/j*_ 토큰은 parts/*.scad·config.scad가 정의하는 import 접근자다.

// NopSCADlib rod.scad는 include 시점에 global_defs로 show_threads를 해석하므로 include 전에 켠다.
$show_threads = true;

include <../parts/base_column_plate_base.scad>
include <../parts/arm_carriage_plate_base.scad>
include <../parts/upper_arm_plate_base.scad>

use <../parts/base_column_motor_plate.scad>
use <../parts/base_column_rod_plate.scad>
use <../parts/arm_carriage_bottom_plate.scad>
use <../parts/arm_carriage_top_plate.scad>
use <../parts/upper_arm_bottom_plate.scad>
use <../parts/upper_arm_top_plate.scad>
use <../parts/motor_seat.scad>
use <../vitamins/flange_bearing_blocks.scad>
use <../vitamins/flange_couplings.scad>

use <NopSCADlib/vitamins/ball_bearing.scad>
use <NopSCADlib/vitamins/belt.scad>
use <NopSCADlib/vitamins/leadnut.scad>
use <NopSCADlib/vitamins/linear_bearing.scad>
use <NopSCADlib/vitamins/nut.scad>
use <NopSCADlib/vitamins/pillar.scad>
use <NopSCADlib/vitamins/pulley.scad>
use <NopSCADlib/vitamins/screw.scad>
use <NopSCADlib/vitamins/shaft_coupling.scad>
use <NopSCADlib/vitamins/stepper_motor.scad>
use <NopSCADlib/vitamins/washer.scad>

// ============================================================
// 변수
// ============================================================

/* [Hardware visibility] */
show_fasteners = true;            // bolts, washers, nuts, standoffs/spacers.
show_motion_components = true;    // motors, belts, pulleys, bearings.
show_remaining_components = true; // rods, lead screws, couplings, leadnuts, and other vitamins.

/* [Preview] */
// 분해 간격(explode step) — 0이면 안착 스택. 키우면 각 관절 스택을 Z축으로 단계별로 벌린다(mm/단계).
robot_j1_exploded = 0; // [0:0.5:30]
robot_j2_exploded = 0; // [0:0.5:30]
robot_j3_exploded = 0; // [0:0.5:30]
// J2 모터 슬롯 위치 — 슬롯홀을 따라 모터를 옮겨 벨트 장력을 본다. 0=near(최소 장력), 1=far(최대 장력).
robot_j2_motor_slot_fraction = 0.5; // [0:0.01:1]
// J1 암-캐리지 높이 — 매달린 상완이 하부 베이스 판을 비키도록 충분히 높게 둔다.
robot_arm_carriage_z = 80; // [0:1:150]
// J2 어깨축 회전각.
robot_j2_angle = 0; // [-180:1:180]
// AC측 FC8 허브 하단과 상판 BB608 내륜 사이 축방향 여유. 0=직접 스택 접촉.
robot_j2_coupling_gap = 0; // [0:0.1:2]

/* [Hidden] */
// 아래는 위 입력에서 도출되는 파생값 — Customizer에 노출하지 않는다(함수는 hoist되므로 정의보다 먼저 참조해도 된다).

// 미리보기 색 — 상/하판·구동/종동 풀리·벨트.
robot_col_top_plate     = [0.18, 0.42, 0.62];
robot_col_bottom_plate  = [0.16, 0.30, 0.40];
robot_col_drive_pulley  = [0.85, 0.58, 0.18];
robot_col_driven_pulley = [0.78, 0.38, 0.18];
robot_col_belt          = [0.02, 0.02, 0.025];
robot_col_belt_tooth    = [0.18, 0.18, 0.18];

// ---- J1 베이스 컬럼 (Z 이송) ----
robot_j1_col_upper_rod_plate = [0.20, 0.36, 0.44];
robot_j1_col_lower_rod_plate = [0.14, 0.28, 0.34];
robot_j1_col_motor_plate     = [0.18, 0.42, 0.62];

robot_j1_ex_lower_kfl       = -3;
robot_j1_ex_lower_rod_plate = -2;
robot_j1_ex_rods            =  0;
robot_j1_ex_upper_kfl       =  1;
robot_j1_ex_upper_rod_plate =  2;
robot_j1_ex_gap             =  3;
robot_j1_ex_motor_plate     =  4;
robot_j1_ex_motor           =  5;

robot_j1_fc_seat_depth  = min(fc_flange_thickness(j1_flange_coupling_type),
                              bc_plate_thickness - seat_shoulder_thickness);
robot_j1_kfl_seat_depth = min(kfl_thickness(j1_flange_bearing_block_type),
                              bc_plate_thickness - seat_shoulder_thickness);
robot_j1_fc_top_seat_z     = bc_plate_thickness - robot_j1_fc_seat_depth;
robot_j1_fc_bottom_seat_z  = robot_j1_fc_seat_depth;
robot_j1_kfl_top_seat_z    = bc_plate_thickness - robot_j1_kfl_seat_depth;
robot_j1_kfl_bottom_seat_z = robot_j1_kfl_seat_depth;

robot_j1_motor_face_local_z = robot_motor_face_local_z(j1_motor_type, bc_plate_thickness);
robot_j1_motor_face_z       = bc_motor_plate_z + robot_j1_motor_face_local_z;
robot_j1_motor_shaft_tip_z  = robot_j1_motor_face_z - NEMA_shaft_length(j1_motor_type);
robot_j1_fc_screw_type      = fc_screw(j1_flange_coupling_type);
robot_j1_fc_screw_length    = screw_length(robot_j1_fc_screw_type, bc_plate_thickness, 2, nut = true);
robot_j1_kfl_screw_type     = kfl_screw(j1_flange_bearing_block_type);
robot_j1_kfl_screw_length   = screw_length(robot_j1_kfl_screw_type, bc_plate_thickness, 2, nut = true);
robot_j1_motor_screw_type   = M3_cap_screw;
robot_j1_motor_screw_length = screw_longer_than(robot_j1_motor_face_local_z + 4);
robot_j1_shaft_coupling_center_local_z = bc_plate_thickness + bc_plate_gap / 2;
robot_j1_shaft_coupling_center_z       = bc_upper_rod_plate_z + robot_j1_shaft_coupling_center_local_z;
robot_j1_shaft_coupling_bottom_z       = robot_j1_shaft_coupling_center_z - sc_length(j1_shaft_coupling_type) / 2;
robot_j1_shaft_coupling_top_z          = robot_j1_shaft_coupling_center_z + sc_length(j1_shaft_coupling_type) / 2;

robot_j1_guide_rod_bottom_z  = robot_j1_fc_top_seat_z;
robot_j1_guide_rod_length    = smooth_rod_length(j1_guide_rod_type);
robot_j1_guide_rod_top_z     = robot_j1_guide_rod_bottom_z + robot_j1_guide_rod_length;
robot_j1_lead_screw_bottom_z = robot_j1_kfl_top_seat_z;
robot_j1_lead_screw_length   = lead_screw_length(j1_lead_screw_type);
robot_j1_lead_screw_top_z    = robot_j1_lead_screw_bottom_z + robot_j1_lead_screw_length;

// ---- J2 암 캐리지 (어깨) ----
// 슬라이더가 가리키는 모터 중심 — 부품(슬롯)은 고정이고, 이 좌표만 모터·구동 풀리·벨트 미리보기를 따라 움직인다.
robot_j2_motor_position = ac_j2_motor_center_at(robot_j2_motor_slot_fraction);

// Z 분해 레벨 — 안착 위치에 level×robot_j2_exploded를 더해 스택 순서대로 벌린다. 음수=아래, 양수=위, 0=갭 중앙(고정).
robot_j2_ex_lock_nut       = -4;  // J2 락너트 — 하판 아래로 가장 멀리
robot_j2_ex_bottom_screw   = -3;  // 하판 스탠드오프 볼트
robot_j2_ex_bottom_bearing = -2;  // 하판 BB608 — 하판 포켓에서 아래로 빠짐
robot_j2_ex_bottom_plate   = -1;
robot_j2_ex_gap            =  0;   // 필러·선형 베어링·종동 풀리(갭 중앙 고정)
robot_j2_ex_lead_nut       =  1;   // 리드너트 — 상판 아랫면 포켓에서 아래로 빠짐
robot_j2_ex_leadnut_screw  =  1;   // 리드너트 플랜지 볼트(아래에서 삽입)
robot_j2_ex_top_plate      =  2;
robot_j2_ex_top_bearing    =  3;   // 상판 BB608 — 상판 포켓에서 위로 빠짐
robot_j2_ex_drive_pulley   =  3;
robot_j2_ex_top_screw      =  3;   // 상판 스탠드오프 볼트
robot_j2_ex_leadnut_nut    =  3;   // 리드너트 플랜지 너트(상판 위)
robot_j2_ex_motor          =  4;

// 스택 높이 좌표 — 상판 윗면, 모터 페이스(상판 윗면에서 내려앉음), 모터 샤프트 끝.
robot_j2_top_plate_z        = ac_thickness + ac_plate_gap;
robot_j2_motor_face_local_z = robot_motor_face_local_z(j2_motor_type, ac_thickness);
robot_j2_motor_face_z       = robot_j2_top_plate_z + robot_j2_motor_face_local_z;
robot_j2_motor_shaft_tip_z  = robot_j2_motor_face_z - NEMA_shaft_length(j2_motor_type);

// 풀리 공통 평면 Z — 가용 구간의 하한을 잡는다(상한 _max는 assert 검증용).
robot_j2_belt_center_z_min = robot_belt_center_z_min(ac_thickness, robot_j2_motor_shaft_tip_z,
                                                     j2_drive_pulley_type, j2_driven_pulley_type);
robot_j2_belt_center_z_max = robot_belt_center_z_max(robot_j2_top_plate_z, robot_j2_motor_face_z,
                                                     j2_drive_pulley_type, j2_driven_pulley_type);
robot_j2_belt_center_z        = robot_j2_belt_center_z_min + eps;
robot_j2_drive_pulley_local_z = robot_drive_pulley_local_z(robot_j2_belt_center_z, robot_j2_top_plate_z);
robot_j2_drive_pulley_screw_z = robot_drive_pulley_screw_z(robot_j2_belt_center_z, j2_drive_pulley_type);

robot_j2_standoff_screw_length = screw_longer_than(ac_thickness + 6);   // 판 두께 지나 ff 필러에 ~6mm 체결

robot_j2_timing_belt_type  = pulley_belt(j2_drive_pulley_type);
robot_j2_timing_belt_pitch = belt_pitch(robot_j2_timing_belt_type);

// GT2 폐루프 표준 벨트 후보(BOM 참조) — near는 올림, far는 내림, current는 반올림한 피치 배수. robot_j2_belt_length() 함수로 도출.
robot_j2_timing_belt_standard_min = ceil (robot_j2_belt_length(0) / robot_j2_timing_belt_pitch) * robot_j2_timing_belt_pitch;
robot_j2_timing_belt_standard_max = floor(robot_j2_belt_length(1) / robot_j2_timing_belt_pitch) * robot_j2_timing_belt_pitch;
robot_j2_timing_belt_standard_mid = round(robot_j2_belt_length(robot_j2_motor_slot_fraction) / robot_j2_timing_belt_pitch) * robot_j2_timing_belt_pitch;

// ---- J3 상완 (팔꿈치) ----
// 상/하판 간격 — J3 벨트 구동이 들어갈 표준 판 간격. 근위 J2 축은 AC 상단 FC8 허브와 맞물린다.
robot_j3_plate_gap   = pillar_height(standoff_pillar_type);
robot_j3_top_plate_z = ua_thickness + robot_j3_plate_gap;

robot_j3_ex_lock_nut       = -3;  // J3 락너트 — 하판 아래로 가장 멀리
robot_j3_ex_bottom_bearing = -2;  // 하판 BB608
robot_j3_ex_bottom_plate   = -1;
robot_j3_ex_gap            =  0;   // 종동 풀리·벨트(갭 중앙)
robot_j3_ex_top_plate      =  1;
robot_j3_ex_top_bearing    =  2;   // 상판 BB608
robot_j3_ex_drive_pulley   =  2;
robot_j3_ex_motor          =  3;
robot_j3_ex_shoulder_bolt  =  4;   // J3 숄더 볼트 — 위로 가장 멀리

robot_j3_motor_face_local_z = robot_motor_face_local_z(j3_motor_type, ua_thickness);
robot_j3_motor_face_z       = robot_j3_top_plate_z + robot_j3_motor_face_local_z;
robot_j3_motor_shaft_tip_z  = robot_j3_motor_face_z - NEMA_shaft_length(j3_motor_type);
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

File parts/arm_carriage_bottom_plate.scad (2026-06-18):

// parts/arm_carriage_bottom_plate.scad - J1 carriage bottom plate (NopSCADlib printed-part style).
// The Z-mirror of the top plate, sharing the same arm-carriage blank, but with no motor: the motor mounts on the top
// plate only. Its back (-Y) lobe is sized to the 20T drive pulley footprint over the motor-slot travel instead of
// the motor footprint, since only the pulley reaches this plate. The remaining bearing seats mirror the top plate.
//
// J1 캐리지 하판 — 상판과 같은 블랭크를 쓰는 Z 미러. 단, 모터는 없다(모터는 상판에만 단다).
// 뒤쪽(−Y) 로브는 모터 풋프린트가 아니라 20T 구동 풀리 풋프린트(풀리 외경 + component_margin)에 맞추고,
// 모터 슬롯 가동 길이 전체를 덮는다 — 이 판엔 풀리만 닿기 때문이다.
// 리드너트도 없다(너트는 상판에만) — 하판은 리드스크류만 자유 관통한다.
// 나머지 형상(종동 베어링·가이드 로드 베어링 시트)은 상판과 같되, 시트가 열리는 면만 뒤집는다(from_top 반전).

include <arm_carriage_plate_base.scad>
use <ball_bearing_seat.scad>

module arm_carriage_bottom_plate() {
    difference() {
        // 뒤쪽(−Y) 로브 = 20T 풀리 슬롯 로브 + LM8UU 캡처 칼라(양형, 윗면). 구동 풀리의 Y 이동 범위를 모두 덮는다.
        union() {
            ac_plate_base()
                ac_drive_pulley_slot_lobe();

            ac_linear_bearing_bosses(from_top = true);
        }

        // J2 종동 베어링 시트 — 상판(from_top=true)의 Z 미러: 아랫면으로 연다.
        translate(j2_driven_axis_center)
            bb_bearing_seat_pocket(j2_driven_ball_bearing_type, part_thickness = ac_thickness, from_top = false);

        // J1 리드스크류 관통 보어 — 하판엔 리드너트가 없다(너트는 상판에만). 리드스크류만 판을 자유 관통한다.
        translate([j1_axis_center[0], j1_axis_center[1], -eps])
            cylinder(d = leadnut_bore(j1_leadnut_type) + shaft_clearance, h = ac_thickness + eps * 2);

        // 가이드 로드 LM8UU 시트(음형, 윗면) — 상판의 Z 미러. 필러 간격이 베어링보다 짧을 때만 깎인다.
        ac_linear_bearing_seats(from_top = true);
    }
}

arm_carriage_bottom_plate();

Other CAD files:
parts/arm_carriage_plate_base.scad
assemblies/annotations.scad
main.scad
parts/arm_carriage_top_plate.scad
parts/ball_bearing_seat.scad
parts/base_column_motor_plate.scad
parts/base_column_plate_base.scad
parts/base_column_rod_plate.scad
parts/bearing_inner_race_boss.scad
parts/bearing_seat.scad
parts/column_carriage_plate_base.scad
parts/flange_bearing_block_seat.scad
parts/flange_coupling_seat.scad
parts/j2_hub.scad
parts/leadnut_seat.scad
parts/linear_bearing_seat.scad
parts/motor_seat.scad
parts/upper_arm_bottom_plate.scad
parts/upper_arm_plate_base.scad
parts/upper_arm_top_plate.scad
utils/placement.scad
utils/plate.scad
vitamins/flange_bearing_blocks.scad
vitamins/flange_blocks.scad
vitamins/flange_couplers.scad
vitamins/flange_couplings.scad
vitamins/pillars.scad
vitamins/pulleys.scad
vitamins/rods.scad
vitamins/screws.scad

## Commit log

2026-06-16 Add initial implementation of cobot-nano robot arm
    - Created README.md with project overview, design, layout, workflow, and BOM.
    - Added elbow assembly module in assemblies/elbow_assembly.scad.
    - Introduced configuration settings in config.scad for project-wide parameters.
    - Included various images for documentation in docs/images/.
    - Documented kinematic chain structure in docs/kinematic_chain.md.
    - Implemented batch export script for DXF files in export/make_dxf.sh.
    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
    [base_mounting_plate.scad, bearing_inner_race_boss.scad, config.scad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]
2026-06-16 Refactor arm carriage assembly
    [arm_carriage_assembly.scad, arm_carriage_housing.scad, arm_carriage_plate.scad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]
2026-06-16 Refine arm carriage belt hardware
    [arm_carriage_assembly.scad, arm_carriage_housing.scad, arm_carriage_plate.scad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]
2026-06-16 refactor(arm_carriage): cut dependent vars, unify naming, sync docs to SCARA/3D-print
    Code (geometry-preserving):
    - config: remove dead values (MAX_REACH, BB6805, explode_distance,
    plate_thickness); reuse NopSCADlib `eps`; relocate local vitamin types
    - vitamins/screws.scad, vitamins/pulleys.scad: local M6_shoulder_screw /
    GT2x60x8_pulley mirroring NopSCADlib family-per-file
    - parts/bearing_seat.scad: consolidate bearing_seat_pocket +
    bearing_inner_race_boss (replaces vitamins/ball_bearings.scad and
    parts/ball_bearing_inner_race_boss.scad); bb_* -> bearing_*
    - plate_base: extract j2_belt_envelope_y(); inline single-use vars;
    ac_thickness -> ac_plate_thickness, shoulder_motor -> mot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
    [arm_carriage_assembly.scad, arm_carriage_housing.scad, arm_carriage_plate.scad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]
2026-06-16 feat(idler): integral 5mm-bore-bearing GT2 idler + standardize fasteners to off-the-shelf sizes
    - idler: replace the solid GT2x20 idler on an M4 screw (could not spin)
    with a one-piece GT2x20 toothed idler that has an integral 5mm-bore
    bearing, on an M5 axle, so it spins freely. New local type
    GT2x20_idler_5mm in vitamins/pulleys.scad; idler screw M4 -> M5.
    - fasteners: snap lengths to NopSCADlib's standard ladder via
    screw_longer_than / screw_shorter_than -- standoff M3x16, leadnut
    M3x12, idler M5x50, driven-axis shoulder bolt M6x50. Standoffs
    snap-down (engage pillar, head flush); nut/nyloc joints snap-up.
    - BOM: update to standard sizes + integral-bearing idler.
    Compiles clea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
    [arm_carriage_assembly.scad, arm_carriage_plate_base.scad, pulleys.scad]
2026-06-16 refactor(bushings): print idler/axis spacers, drop sub-printable ones
    - spacers are 3D-printed positioning bushings: render only when
    height >= min_printed_feature (0.8mm, ~2 FDM layers). Thinner gaps
    (e.g. driven-axis upper 0.17mm) are omitted and taken up by the washer.
    - config: add min_printed_feature
    - BOM: relabel spacers as printed bushings
    [arm_carriage_assembly.scad, config.scad]
2026-06-16 chore: remove legacy 4-bar palletizer parts (SCARA pivot)
    elbow_assembly, forearm, motor_bracket and upper_arm belonged to the old
    4-bar palletizer design. The project is now a SCARA arm, so these are removed.
    [elbow_assembly.scad, forearm.scad, motor_bracket.scad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]
2026-06-16 feat(j2-hub): upper-arm mounting hub on the J2 (shoulder) axis
    New parts/j2_hub.scad: a printed hub that clamps to the rotating J2 output
    around the shoulder bolt and presents a 4x M3 bolt circle for the upper arm.
    One hub above the top plate and one below the housing let the upper arm
    connect on either or both faces.
    [j2_hub.scad]
2026-06-16 feat(standoffs): 6-point layout for even plate clamping
    Add two disc top/bottom standoffs at [0, +-z_shaft_center_distance]; the two
    plates are now clamped evenly around the disc (the driven axis is already
    clamped by the shoulder bolt, idlers/leadnut by their own bolts). All keepout
    asserts pass. BOM standoff count 4 -> 6.
    [arm_carriage_plate_base.scad]
2026-06-16 feat(viz): function colour-coded labels + radial bloom exploded view
    - assemblies/annotations.scad: preview-only callout labels (leader line +
    camera-facing billboard text). Colour is passed in resolved; the emphasis
    flag thickens the leader and bolds the text for axes/links.
    - assembly: ac_part_labels data list + label_colour() keyed by function
    (printed=blue, bearing, transmission, motor, leadnut, fastener); tone-on-tone
    shades spread within each group so no two parts share a colour; parts are
    coloured to match the labels; longer leaders.
    - at_xy() blooms parts radially from the origin when exploded, distance-
    proportional, down to bolts/nuts/washers/bushings.
    - place the J2 up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
    [annotations.scad, arm_carriage_assembly.scad]
2026-06-17 feat(base-column): J1 vertical lead-screw column
    Fixed base column capturing the J1 lead screw and two guide rods between
    two end plates, sharing the arm-carriage J1 axis frame so the carriage
    slides on the same axes.
    - KFL08 flange bearing (modelled to datasheet: diamond flange + insert
    bearing) supports the rotating T8 lead screw top and bottom
    - FC8 flange couplers fix the two 8mm guide rods to the plates
    - central NEMA17 under the lower plate drives the screw via a GT2 belt (20T -> 60T)
    - local vitamins flange_blocks.scad (KFL08) and flange_couplers.scad (FC8),
    mirroring NopSCADlib family-per-file style
    - bc_rod_centers + bc_place_support_ends keep placement DRY
    docs/images/kfl08_r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
    [base_column_assembly.scad, base_column_bottom_plate.scad, base_column_plate_base.scad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]
2026-06-17 feat(viz): part-label callout overlay for arm carriage
    Preview-only callout labels: camera-facing billboard text with leader
    lines, auto-placed in two screen columns from the viewport so they do not
    overlap or occlude the model.
    - annotations.scad: billboard text, screen-basis functions, one_callout
    (multi-leader per instance), callout_field auto-layout, stack_sequence
    - arm_carriage_assembly.scad: ac_part_labels data, three category toggles
    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
    [annotations.scad, arm_carriage_assembly.scad]
2026-06-17 fix(arm-carriage): add motor shaft bore through top plate
    The flipped J2 motor seats in the plate recess with its shaft pointing
    down to a pulley below the plate, but the boss recess left a solid
    seat-shoulder floor that blocked the shaft. Add a central shaft
    through-bore (NEMA_shaft_dia + shaft_clearance).
    [arm_carriage_plate.scad]
2026-06-17 feat(arm-carriage): inner-race hub boss, repositioned J2 stack, bolt-circle standoffs
    - j2_hub: inner-race boss (j2_hub_boss_diameter) + j2_hub_height() accessor
    so the hub grips only the spinning inner race, clear of shield/outer race
    - J2 driven-axis stack: shoulder-bolt head/washer and nyloc moved to the hub
    outer faces, bolt lengthened by 2x hub height
    - standoffs: replaced the 6 hand-placed pillars with a filtered bolt circle
    (ac_standoff_clear predicate over even candidates) -> 10 standoffs; labels
    now show the live count
    [arm_carriage_assembly.scad, arm_carriage_plate_base.scad, j2_hub.scad]
2026-06-17 feat(assembly): combined J1 Z-stage with single-source shared shafts
    New column_carriage_assembly combines the base column and arm carriage on
    one J1 axis and is the sole owner of the shared lead screw + guide rods
    (the column captures them in its KFL/FC holders; the carriage rides them).
    - base_column_assembly: no longer draws the screw/rods
    - arm_carriage_assembly: dropped its duplicate J1 shaft stub, the
    show_j1_shaft toggle, ac_j1_shaft_* vars and the two shaft labels
    - base_column_plate_base: now datums only (bc_top_face_z); the shaft spans
    and draw module moved to the combined assembly (parts/ stays vitamin-free)
    - dependencies stay one-way: config -> arm_carriage_plate_base ->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
    [arm_carriage_assembly.scad, base_column_assembly.scad, base_column_plate_base.scad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]
2026-06-17 feat(base-column): top-mounted J1 drive, independent motor, shared motor-seat
    - J1 motor mounts on the top plate pointing down (like the J2 motor); the
    bottom plate is now a plain capture plate
    - 20T lead-screw pulley (local GT2x20x8, bore 8) -> 1:1 with the motor
    - bc_motor_type makes the J1 motor independent of the carriage ac_motor_type
    - show_hardware toggle on base_column / arm_carriage / column_carriage
    (propagates to sub-assemblies and the shared lead screw / rods)
    - refactor: shared nema_motor_seat() 2-step seat cut replaces the duplicated
    J1/J2 motor recess; boss bore comes from the passed motor type; dropped the
    now-redundant recess-depth and boss-radius datums
    Co-Authored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
    [arm_carriage_assembly.scad, arm_carriage_plate.scad, arm_carriage_plate_base.scad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]
2026-06-17 Align arm-carriage parts to base-column pattern; detail base-column J1 drive
    Arm carriage (form-preserving refactor):
    - Split fused arm_carriage_plate_base() into arm_carriage_plate_blank() plus
    shared cut modules (arm_carriage_axis_cuts, arm_carriage_leadnut_recess,
    arm_carriage_linear_bearing_recess(from_top)), mirroring the base-column
    layout. Plate/housing become thin difference() compositions; the leadnut
    and LM8UU recesses are no longer duplicated across the two files.
    KFL clearance (base column):
    - Add kfl_radius() = kfl_length/2 (oval-flange circumscribing radius, like
    NEMA_radius wrapping a motor body). Idler-KFL assert and bc_plate_radius
    now use the full extent instea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
    [arm_carriage_housing.scad, arm_carriage_plate.scad, arm_carriage_plate_base.scad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]
2026-06-17 Refactor arm carriage stack
    [arm_carriage_assembly.scad, arm_carriage_bottom_plate.scad, arm_carriage_housing.scad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]
2026-06-17 Use motor slot for J2 belt tension
    [arm_carriage_assembly.scad, arm_carriage_bottom_plate.scad, arm_carriage_plate_base.scad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]
2026-06-18 feat(arm-carriage): add fastener stack, exploded view, motor-slot controls
    Assembly preview now places all hardware and supports per-part inspection:
    - Fasteners: standoff cap screws + washers (both plate faces), J2
    driven-axis shoulder bolt through both BB608 bores to an M6 nyloc
    locknut, and J1 lead-nut flange screws/nuts. Sizes read from accessors.
    - J2 motor slot: ac_j2_motor_center_at(fraction) takes a normalized
    0=near .. 1=far position; preview slider drives motor, drive pulley,
    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
    [arm_carriage_assembly.scad, arm_carriage_bottom_plate.scad, arm_carriage_plate_base.scad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]
2026-06-18 Add base column assembly and rod vitamins
    [arm_carriage_assembly.scad, arm_carriage_bottom_plate.scad, arm_carriage_plate_base.scad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]
2026-06-18 refactor(arm-carriage): simplify derived vars, extract HOC helpers, trim comments
    Geometry and features unchanged (arm-carriage and base-column echo output
    identical before/after); structure simplified per NopSCADlib +
    OPENSCAD_CONVENTIONS.md (HOC/children, P-4 derived-as-function, C-1/C-5 comments).
    - utils/placement: add bounding_diameter_with_margin (edge-envelope helper,
    distinct from the center-distance packing helper); margin is passed by the
    caller so the util keeps no config-global dependency
    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
    [arm_carriage_assembly.scad, arm_carriage_bottom_plate.scad, arm_carriage_plate_base.scad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]
2026-06-18 refactor(assembly): consolidate subassemblies into one robot_assembly; add J3 upper arm
    Replace the separate base_column / arm_carriage / column_carriage assembly
    files with a single assemblies/robot_assembly.scad that renders the full
    J1 -> J2 -> J3 robot from one flat robot_ namespace and one robot_assembly().
    - assemblies/robot_assembly.scad (new): unified assembly. Shared placement and
    drive-stack helpers deduplicated (standoff pillar/fastener, seated couplings
    and bearing blocks, through-plate fasteners). Organized into variable /
    function / diagnostic / module sections; derived vars hidden from Customizer.
    - assemblies/{base_column,arm_carriage,column_carriage}_assembly.scad: re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
    [arm_carriage_assembly.scad, arm_carriage_plate_base.scad, base_column_assembly.scad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]
